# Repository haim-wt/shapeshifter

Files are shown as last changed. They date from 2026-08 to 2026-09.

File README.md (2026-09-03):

# Shapeshifter

A single-seat, folding, electric assisted glider — hang-glider freedom with
fly-by-wire safety, in a vehicle that drives itself to the launch point.

## The three modes

1. **Drive** — folded (3.9 × 2.5 m footprint), self-propelled on its wheels
   at scooter speeds. Off-road / field / garage-to-launch; not road-legal by
   design. Folded ground handling also removes the classic wind-on-the-ground
   hazard of foot-launched gliders.
2. **Unfold** — two automated fold stages (nested parallelogram
   linkages, all-vertical hinge axes, gravity-neutral), sensor-verified locks. The aircraft will not arm propulsion
   unless every lock confirms.
3. **Fly** — a 10 m joined-wing box glider, L/D ≈ 16–17, with twin electric
   tractor motors for takeoff (~50–70 m of grass), climb, go-around, and
   powered slow landings. Fly-by-wire with a hard flight envelope: stall is
   a software limit, not a pilot skill.

## Configuration at a glance

| | |
|---|---|
| Configuration | joined-wing box (Ligeti Stratos geometry), no tail boom |
| Span / area | 10.0 m / 13.0 m² (4 identical elements, one mold) |
| Empty weight | ~103 kg target (Part 103 cap: 115 kg / 254 lb) |
| Stall (landing config, camber flap) | ≤ 23 kt — Part 103 limit is 24 kt |
| Best glide | L/D ≈ 16–17 at ~16 m/s; min sink ≈ 0.9 m/s |
| Propulsion | 2 × ~3 kW tractor motors, folding props, rear wing LE |
| Battery | modular 2–4 × 0.9 kWh swappable packs + isolated actuator pack |
| Folded | 3.91 × 2.46 × 2.08 m — standard parking space |
| Regulatory | FAR Part 103 ultralight (no license, no certification) |
| Recovery | ballistic parachute (excluded from Part 103 empty weight) |

## Status

Concept definition. See [docs/spec.md](docs/spec.md) for the numbers,
[docs/fold-mechanism.md](docs/fold-mechanism.md) for the fold design,
[docs/mass-audit.md](docs/mass-audit.md) for the mass/battery ledger,
[docs/decisions.md](docs/decisions.md) for the decision record, and
[docs/exploration-history.md](docs/exploration-history.md) for how the
configuration was reached and what was rejected on the way.

## 1:10 printed model

Printable STLs for a Bambu P-series (256 mm cube) live in `models/1to10/`
(`tools/model_geometry.py`); editable STEP solids in `models/1to10/step/`
(`tools/model_step.py`, CadQuery); a native parametric Fusion 360 build
script in `tools/fusion360/`. Build plan, print counts, and test cards in
[docs/model-1to10.md](docs/model-1to10.md).

## Driving Fusion 360 directly

Autodesk's Fusion MCP server (Fusion: *Preferences > General > API > enable
Fusion MCP Server*, default port 27182) is registered in `.mcp.json` as a
project-scoped MCP server. It listens on loopback, so it is reachable only
from a Claude Code session running on the same machine as Fusion:

```
git clone <repo> && cd shapeshifter
git checkout claude/shared-conversation-review-vau7yj
claude            # approve the "fusion" MCP server when prompted
```

Then ask Claude to build the 1:10 model in the open Fusion design — it can
drive Fusion's API live instead of running the blind script in
`tools/fusion360/`.

## Next physical articles (in order)

1. Sub-scale fold mechanism (both parallelogram stages + locks) — the fold
   is the novel mechanism; prove 1-DOF behavior, lock integrity, and
   repeatability before any aerodynamic work.
2. Fin/tip node with stub wings, torsion-tested — the fin carries three
   jobs (joiner, yaw surface, wing-to-"tail" load path); its stiffness is
   the number the stability margin hangs on.
3. One full-scale wing element (D-nose, sail, camber flap, mid-span fold
   joint) — the entire aircraft in miniature.

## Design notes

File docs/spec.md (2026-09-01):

# Shapeshifter — Specification v0.2

Status: concept definition. Every number here is a target with a stated
derivation, not a measured value. Numbers that bind the design are marked
**(binding)**.

## 1. Mission

Single occupant. Drive folded from storage to an open field under its own
power, unfold, take off in ~50–70 m of grass, fly as a genuine glider with
electric assist (launch, saves, go-around, powered slow landing), land,
fold, drive away. Pilot supplies intent; fly-by-wire supplies control and
envelope protection.

## 2. Regulatory envelope — FAR Part 103 (binding)

| requirement | limit | our position |
|---|---|---|
| Empty weight, powered | 254 lb / 115 kg | ~103 kg target + 12 kg margin |
| Ballistic parachute | excluded from empty weight | fitted, ~7 kg physical |
| Power-off stall, landing config | ≤ 24 kt CAS | 22.6–23.1 kt (flap, see §5) |
| Max level speed | ≤ 55 kt | ~35 kt cruise, not binding |
| Occupants | 1 | 1 |

Consequences: no license, no certification, no medical — this is what makes
"as easy as riding a bike" legally true, and it is why Part 103 is a hard
target rather than a preference. It also means nobody certifies the
fly-by-wire system; every safety property is self-imposed (§9).

Fallback if mass discipline fails: MOSAIC LSA (effective 2025-10-22) allows
electric propulsion, no weight cap, 59 kt stall — but requires a sport-pilot
certificate and consensus-standard certification. Different product; avoid.

## 3. Configuration

Joined-wing box: front wing pair low and forward on the capsule, rear pair
high and aft (~1.5 m stagger = tail arm), tips joined by slanted fins.
Decalage ~2.5° makes the front pair stall first — pitch stability and stall
recovery are geometric, not commanded. Four identical wing elements from one
mold; front/rear differ only in root-fitting incidence.

- Span 10.1 m, area 13.0 m², chord 0.72 m constant
- Element per side: 0.24 m fixed root stub + 2.25 m inner panel + 2.25 m
  outer panel (equal spans — a fold requirement, see docs/fold-mechanism.md)
- Effective span ≈ 11.7 m (Prandtl box-wing), effective AR ≈ 10.5
- Section: D-nose torsion box to 30% chord, sail aft, ~14% t/c, morphing
  trailing edge (camber flap) on the front pair
- Moving aerodynamic surfaces in flight: 2 elevons (rear outboard, actuators
  in fin nodes) + camber flaps. Yaw: fins + differential thrust/regen.

## 4. Mass budget (binding — every line is a not-to-exceed)

| group | kg |
|---|---|
| 4 wing elements (13 m², D-nose + sail + flap) | 26 |
| Fins / tip nodes (2) | 6 |
| Fold system: 4 root pivots, 4 mid-span joints, locks, actuators | 12 |
| Capsule survival cell + canopy | 16 |
| Seat, harness, cockpit controls | 4 |
| Landing gear: 3 wheels, 2 hub motors, brakes, suspension | 13 |
| Propulsion: 2 motors, ESCs, folding props, mounts | 9 |
| Flight battery — LiTech 12S6P (RFQ), 1–3 × 1.12 kWh @ ~6.35 kg | 6.4–19.1 |
| Avionics, FBW actuators, actuator battery, wiring | 6 |
| **Empty (Part 103 accounting)** | **98.4–111.1** |
| Ballistic parachute (physical, excluded from Part 103 count) | +7 |
| Pilot (design range 60–100 kg) | +85 nominal |
| **Flying weight, nominal** | **~195 kg** |

Core empty (everything except battery) = 92 kg; battery fills the gap to
the 115 kg cap as swappable modules. Full audit, line justifications, and
the battery-as-residual-claimant rule: **docs/mass-audit.md**.

## 5. Speeds and compliance stall (binding)

At 195 kg flying weight, S = 13.0 m², sea level:

- Stall, clean, CLmax 1.5: 12.3 m/s = 23.9 kt — no margin. Therefore:
- **Stall, landing config, camber flap, CLmax 1.7: 11.9 m/s = 23.1 kt** ✓
  (at 100 kg pilot + chute: 23.5 kt ✓)
- The camber flap is REQUIRED for Part 103 compliance, not an option.
- Rotate ~13.5 m/s; approach ~1.3 Vs ≈ 15 m/s, reduced further by partial
  thrust unloading on final
- Best glide ~16 m/s, L/D ≈ 16–17; min sink ≈ 0.9 m/s at ~13 m/s
- Vne 40 m/s (structural placard, to be confirmed by aeroelastic analysis)

## 6. Propulsion and energy

- 2 × T-Motor P80 III KV100 (ag-drone class, >3.3 kW cont, IP55), rear
  wing leading edge at ±1.2 m, counter-rotating (tops inboard), Ø0.81 m
  (32") CF props — rigid on prototype, folding hub as product item;
  ESC: T-Motor Alpha 80A 12S FOC (LVC off, telemetry to FC)
- Static thrust ~380 N combined (~190 N/motor at ~3.5 kW); + wheel drive
  → grass takeoff roll ~50–60 m
- Climb ~1.0–1.3 m/s at full power (195 kg); one motor = full sustainer
- Cruise/sustain power: ~2.2 kW electrical → 27–80 min powered (1–3 packs); bus 12S (44.4 V nom / 50.4 V max)
- Energy reality: one climb to 500 m costs ~600–700 Wh. The pack buys one
  launch + saves + reserved go-around (~25 Wh, never spendable by the
  planner), or two modest launches. Soaring is the range extender.
- Regen: props windmill under regen for glide-path control (replaces
  spoilers) and descent recovery
- Ground drive: 2 hub motors, 25–40 km/h, ~20 Wh/km — ground range is
  effectively free relative to flight

## 7. Fold architecture (the novel mechanism)

Fully defined in **docs/fold-mechanism.md**; verified by the parametric
model `tools/fold_kinematics.py` (collision-checked through the complete
sequence); figure: docs/fold_sequence.png. Summary:

- Two nested parallelogram linkages, **all hinge axes vertical** → the fold
  is gravity-neutral; actuators are sized by wind (≤ 4 m/s fold limit),
  not by lifting panels.
- Stage 1: outer panels + fin double back 177° about mid-span knuckles
  (fin translates — parallelogram coupler). Stage 2: inner panels scissor
  88° **forward** about 240 mm root stubs; wings wrap the nose.
- **Folded: 3.91 × 2.46 × 2.08 m** — standard parking space.
- Flight loads cross every hinge perpendicular to its free axis: bearing
  couples carry bending (5–6 kN ultimate); locks carry only in-plane
  moments (< 0.7 kN). Two lock groups per side, spring-loaded to locked,
  position-sensed, tapered pins for zero freeplay.
- The fold owns one hull constraint: the footwell (first 0.8 m, below
  z ≈ 0.5) must stay ≤ 0.32 m wide — the doubled front-outer trailing
  edges sweep past it with 18 mm margin.
- Fold is ground-only: interlocked against airspeed and prop arming;
  propulsion cannot arm until all locks confirm and a control sweep passes.

## 8. Ground mode

- Tricycle: two main wheels (hub motors, regen + friction brakes) just aft
  of CG, ~1.1 m track; steerable nosewheel. No self-balancing single wheel:
  static stability, no balance energy, and a stable rollout platform for
  automated landings.
- Off-road self-mobility only (field, campground, private ways). Not
  road-legal, by decision — avoids automotive homologation entirely.
- Drive folded; unfold at the launch point. Deployed taxi is limited to
  walking pace by software (13 m² of wing in a gust is a kite).

## 9. Safety architecture

1. Envelope protection: alpha and load-factor limits in software; stall is
   unreachable by command. Elevon travel limiter implements the guarantee.
2. Redundancy: twin motors (one = sustainer; differential thrust is backup
   yaw/pitch authority after a control failure), dual elevon paths,
   isolated actuator/avionics battery (control survives total propulsion
   pack loss).
3. Interlocks: props cannot arm unless all 6 fold locks confirm + control
   sweep passes; fold cannot actuate with airspeed > 0 or props armed.
4. Ballistic parachute, capsule as survival cell: crushable nose,
   energy-absorbing seat sized for ~7 m/s descent under canopy.
5. Landing assist: powered slow approach (partial thrust unloading),
   propwash over elevons keeps control authority below free-flight stall,
   reserved go-around energy, auto-flare.

## 10. Open risks (ranked)

1. **Fin/tip-node stiffness** — the joined wing's stability margin and the
   propped-beam structural savings both assume a stiff fin loop. Physical
   torsion test before tooling.
2. **Fold-joint stiffness and freeplay** — 6 locked joints now sit in the
   primary structure; lash there is the flutter path. Budget < 0.5 mm at
   the lock, measured, per joint.
3. **Mass growth** — 12 kg margin against Part 103; every kg over cascades
   into the stall limit via §5.
4. **Aeroelastics of the final configuration** — no flutter analysis exists
   yet for the box with fold joints; required before Vne is trusted.
5. **Stage-1 fold collision/clearance geometry** — panels, fin, props, and
   capsule must clear through the full fold arc; resolve in CAD + sub-scale.
6. **Sail behavior at 13 m² with flap** — camber-flap CLmax 1.7 on a
   sail-over-D-nose section is assumed, not demonstrated; wind-tunnel or
   instrumented RC validation.

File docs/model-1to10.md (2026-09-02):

# 1:10 printed model — build plan

Printer: Bambu Lab P2S, 256 × 256 × 256 mm. Geometry: `tools/model_geometry.py`
→ `models/1to10/*.stl` (all watertight, all fit the bed, report in
`parts_report.json`). Preview: `docs/model_1to10_preview.png`.

## What this model is for — and what it is not

**Tests (worth building for):**
1. **The fold, with real locks.** Kinematics scale exactly, so both
   parallelogram stages, the forward scissor, the knuckle z-offset, and the
   lock sequencing are all faithfully represented. Note: *clearances scale
   too* — the full-scale 18 mm footwell margin becomes 1.8 mm here, inside
   print tolerance. If the model binds at the footwell, that is a finding
   about the full-scale margin, not a print defect: the answer is to widen
   the full-scale margin to ≥ 30 mm, not to file the model.
2. **Configuration stability.** Stagger as tail arm, decalage making the
   front pair stall first, spiral/Dutch-roll tendency with these fins —
   all visible in hand-glide tosses before any electronics go in.
3. **Elevon authority and the two-motor control backup** (phase 3).

**Does not test (do not draw conclusions):** aerodynamic coefficients
(Re ≈ 45k at this chord — the 14.3% section will run a laminar bubble and
glide at maybe L/D 6–8; full scale is Re ≈ 800k), flutter, the sail
structure (printed skins are rigid), mass properties, or actuator loads.

## Geometry at 1:10

| item | full scale | model |
|---|---|---|
| Span | 10.1 m | 1,010 mm |
| Chord | 0.72 m | 72 mm |
| Root stub / inner / outer panel | 0.24 / 2.25 / 2.25 m | 24 / 225 / 225 mm |
| Stagger / gap | 1.50 / 1.40 m | 150 / 140 mm |
| Fin | 2.05 m × 0.35 m, 12% | 205 × 35 mm |
| Pod | 2.1 × 0.74 × 1.4 m | 210 × 74 × 140 mm |
| Outer-panel washout | 3° | 3° (built into the STL) |
| Decalage | front +2.5° vs rear | built into `root_stub_front` |
| Knuckle z-offset | 120 mm | 12 mm (`hinge_lug_offset`) |
| Wing area | 13.0 m² | 0.135 m² |

## Parts and print counts

| STL | qty | material | orientation / notes |
|---|---|---|---|
| `wing_inner` | 4 | LW-PLA | span-vertical, as printed (no twist → not chiral) |
| `wing_outer` | 2 + 2 **mirrored** | LW-PLA | span-vertical. **Chiral:** washout has handedness. Print 2, then mirror in Bambu Studio **along Z (the print/span axis)** and print 2. Do NOT mirror X — that reverses the chord. (The STEP set ships `wing_outer_L` and `_R` pre-mirrored.) |
| `fin_blank` | 2 | LW-PLA or PLA | vertical; 3.2 mm spar hole |
| `root_stub_front` / `_rear` | 2 + 2 | PETG | these carry the decalage; glue to pod |
| `capsule_pod` | 1 | PLA / PETG | lying on its side; 3 walls, 0–4% infill; nose taper *is* the footwell (fold-critical) |
| `hinge_lug` | 24 | PETG | flat; 3.2 mm hole for M3 pins |
| `hinge_lug_offset` | 8 | PETG | flat; the 12 mm knuckle z-offset lugs |

Slicer settings for the LW-PLA airfoils: 2 walls (0.42 mm), 0% infill,
no top/bottom layers except 2 at the ends, 0.16–0.20 mm layers, LW-PLA
foaming temp per the filament (typically 230–250 °C, flow ~50%), dry the
spool, slow (≤ 60 mm/s). Spar and pin holes are through-holes along the
print axis, so they print clean without supports.

## Hardware (glider phase)

- Spars: 8 × carbon tube Ø5 × 225 mm (one per panel; the fold joints break
  the spar, as they do full scale). Alignment pins: 8 × carbon rod Ø2 × 30 mm.
- Fin spars: 2 × carbon rod Ø3 × 205 mm.
- Fold pins: M3 × 16 screws with nyloc nuts as hinge pins (12 knuckles: 4 root
  pivots, 4 mid-span knuckles, 4 fin-tip hinges). Fold locks: 4 mm Ø
  neodymium magnet pairs at the deployed position (phase 1), replaced by a
  9 g servo-driven pin (phase 2) to test the interlock logic.
- CA + kicker for PETG lugs to LW-PLA; epoxy for spars in the pod stubs.

## Mass and CG

Estimate: 8 panels ≈ 140 g, fins 16, pod ≈ 70, stubs 8, lugs/pins 25,
spars 40 → **~300 g airframe.** Glider-phase electronics (4 × 9 g servos,
RX, 1S 500 mAh) ≈ 60 g → ~360 g before ballast. Powered (phase 3): + 2 ×
(2204 motor, 12 A ESC, 5" prop) + 3S 850 mAh ≈ +210 g → ~570 g.

Wing loading ≈ 4.2 kg/m² powered → flies at ~9–12 m/s. That is faster than
Froude scaling would give (~4 m/s) because the model is ~3× "scale weight";
expected and acceptable — the fold and the stability signatures do not
depend on it.

**First CG guess: 115–120 mm aft of the nose** (≈ 10% of the stagger ahead
of the estimated neutral point at ~130 mm, taking the rear pair at ~70%
efficiency in the front pair's downwash). Start nose-heavy; move aft by
5 mm steps on glide tosses until the glide flattens without hunting.

## Build phases and test cards

**Phase 1 — bench article (no electronics).** Print, spar, assemble both
sides on the pod with magnet locks. Tests: (a) fold both stages by hand;
photograph every interference; (b) measure freeplay at each lock with a
dial indicator against the panel tip; (c) hang 200 g at each tip node
deployed — the propped-beam box should barely deflect; note any joint
that opens. Record in `docs/test-log.md` (create on first test).

**Phase 2 — hand-glide.** Ballast to CG, toss on grass. Looking for:
straight glide, no pitch hunting (decalage working), no wing-drop at the
end of the glide (front stalls first), spiral tendency. Then deliberately
mis-rig: rear stubs at 0° vs front 0° (no decalage) to confirm it matters.

**Phase 3 — RC.** Elevons on the rear outer panels (cut 25% chord, tape
hinges — the flexure idea, cheaply), 2 motors on the rear inner panels at
±120 mm, differential-thrust yaw. Fold servos + lock pins with the
"cannot arm unless locked" interlock in the flight controller — the
first end-to-end exercise of the safety logic.

## Fusion 360 / CAD workflow

Three routes, from quickest to most editable:

1. **STL** (`models/1to10/*.stl`) — slice and print. Not editable.
2. **STEP** (`models/1to10/step/*.step`, from `tools/model_step.py` via
   CadQuery/OpenCascade) — true B-rep solids. *File > Insert > Insert
   Derive* or drag into Fusion: they land as editable bodies you can add
   fillets, pockets, and joints to. This set is one revision ahead of the
   STLs: **hinge-lug pockets are cut into every panel end** on the 25% chord
   line (5.4 × 10 mm deep, through the section) so lugs register instead
   of being placed by eye; the spar hole sits on the twist axis; alignment
   pins are 20 mm blind holes at each end; `wing_outer_L/R` are both
   provided.
3. **Native parametric** (`tools/fusion360/Shapeshifter1to10/`) — a Fusion
   360 API script that rebuilds everything as Fusion features with user
   parameters (`ss_chord`, `ss_inner`, `ss_washout`, `ss_decalage`, …).
   Copy the folder into Fusion's `API/Scripts/` directory, open a new
   design, *Utilities > Add-Ins > Scripts > Run*. Edit any `ss_*` value in
   *Modify > Change Parameters* and the model regenerates. This script was
   written without a Fusion instance to test on; if it errors, paste the
   traceback from the message box and it will be fixed.

## Known limitations of this geometry (v0)

- Panels are solid lofts; skins come from slicer wall settings, not modeled
  ribs. Fine for LW-PLA at this size.
- STL panels have no lug pockets (placement by hand at 25% chord); the
  STEP and Fusion versions do.
- Pod is a clean loft with no canopy line, hatch, or gear — a shape and
  mass placeholder. The nose taper approximates the footwell requirement.
- No nacelles yet; phase-3 motors mount on printed saddles.

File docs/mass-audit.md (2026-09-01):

# Mass audit v1 — every kilogram justified, battery as the residual claimant

Goal restated: the point of mass discipline is not a lighter vehicle — it is
**more battery**. This document sets the algebra that converts saved mass
into energy, then justifies every line.

## 1. The constraint algebra

Three independent caps:

1. **FAA empty weight** (Part 103): empty ≤ 115 kg, *battery included*,
   ballistic chute excluded.
2. **Stall** (Part 103, landing config ≤ 24 kt): at S = 13 m², CLmax 1.7
   → max flying weight **210 kg** (we operate to 205 for margin).
3. **Folded envelope** (parking space): fixed by the fold design, not mass.

Define **core empty = everything except battery**. Then:

- **Max battery = 115 − core.** Today core = 92 kg → max battery 23 kg.
- **At full battery, max pilot = 205 − 115 − 7 (chute) = 83 kg** — and this
  is *invariant*: shrinking core raises battery, not pilot allowance.
  Heavier pilots fly with fewer modules (see §3).

**The exchange rate: 1 kg of core saved = 1 kg of battery = ~160 Wh
= ~95 m of powered climb or ~4 min of sustain.** Every design argument
about mass now terminates in this number.

## 2. Line-by-line justification (core = 92 kg)

| line | kg | basis | confidence | path to battery |
|---|---|---|---|---|
| Wing panels, 4× (13 m² total) | 26 | 2.0 kg/m², D-nose + sail + battens + flap; comparable: ATOS-class rigid wings ~2.3 kg/m² incl. control frame | med | none — already aggressive; growth risk +2 |
| Fins / tip nodes, 2× | 6 | 0.7 m² surface + elevon actuator + propped-beam reaction fitting each | med | none; growth risk +2 (stiffness-critical part) |
| Fold system | 12 | model-derived: 4 root pivots (bearing couples @5.7 kN ult) ~1.3 ea; 4 mid knuckles (@5.3 kN) ~0.9 ea; 6 locks ~0.25 ea; 4 fold drives ~0.45 ea | med-high (loads computed) | **−1**: gravity-neutral fold means sub-kg drives; consolidate stage-1 drive to one side at a time |
| Capsule cell + canopy | 16 | 2.1 m carbon monocoque + bubble; sailplane forward-fuselage comparables 12–18; crash cell adds | med | none — safety-critical line |
| Seat, harness, controls | 4 | includes energy-absorbing seat stroke (chute descent ~7 m/s) | high | none |
| Landing gear + ground drive | 13 | 3 wheels, suspension, brakes + 2 hub motors @3.5 kg | high | **−3**: one driven main + freewheel + steered nose. Ground spec (30 km/h, grass) needs ~2 kW, not two motors. Takeoff traction: verify single-wheel slip on wet grass before committing |
| Propulsion | 9 | 2 × 3 kW outrunners ~1.4 ea, ESCs, Ø1.05 folding props ~0.9 ea, over-wing mounts | high | none |
| Avionics + FBW | 6 | 2 elevon + 2 flap actuators, FC + IMU + air data, isolated 150 Wh actuator pack (~1.0), wiring | med | none; growth risk +1 (wiring always grows) |
| **Core empty** | **92** | | | **identified: −4 → core 88** |

Growth risks total +5; identified savings −4. Honest expectation: core
stays 88–95. **Rule from here: any kilogram added must name the kilogram
it displaces or the watt-hours it forfeits.** Battery absorbs every saving
and every bust — it is the flexible line, by design.

## 3. Battery architecture: modular, and the W&B is measured

**Selected: LiTech 12S6P (RFQ from adopted 13S6P design) — 1–3 swappable
packs × ~1.12 kWh, ~6.35 kg each (~176 Wh/kg, CAN BMS, IP65).** Bus: 12S,
44.4 V nom / 50.4 V max. See docs/parts-log.md. One-hand carry, charge
off-vehicle, no charging infrastructure needed at the field.

The vehicle weighs itself: load cells in the three gear legs give total
weight and CG at power-on. Software enforces MTOW 205 kg and CG limits —
module count is the trim variable:

| pilot | packs | battery | flying wt | powered endurance* | cumulative climb* |
|---|---|---|---|---|---|
| ≤ 87 kg | 3 | 3.35 kWh | ≤ 205 | ~80 min | ~1730 m |
| ≤ 93 kg | 2 | 2.23 kWh | ≤ 205 | ~53 min | ~1150 m |
| ≤ 100 kg | 1 | 1.12 kWh | ≤ 205 | ~27 min | ~580 m |

*usable 88% of nominal; sustain ~2.2 kW; climb conversion ~0.32 (drag paid
during climb); go-around reserve (~25 Wh) always withheld by the planner.

This turns the Part 103 weight problem into a UX feature: the aircraft
tells you how many modules today's pilot + mission can carry, and refuses
to arm overweight. Nothing is placarded on trust.

## 4. What we deliberately do NOT chase

- Sub-2.0 kg/m² wings, exotic capsule layups, titanium anything: each buys
  1–3 kg at large cost and schedule risk; the same money buys pack-level
  Wh/kg, which scales all four modules at once.
- Removing the second flight motor: −4.5 kg, but redundancy is a standing
  owner decision (D-006).
- Removing gear/suspension travel: it is the landing-assist crumple margin
  and the W&B sensor mount.

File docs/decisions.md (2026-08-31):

# Decision record

Short, dated entries. A decision stands until a dated entry reverses it.
(The exploration phase showed why this file exists: good decisions were
made, lost, and re-derived. Not again.)

## D-001 · 2026-08-31 · Regulatory envelope: FAR Part 103, hard target
No pilot license, no certification, no medical — the only regime where the
product promise is legally true. Consequences: 115 kg empty cap, 24 kt
stall in landing configuration, single seat. MOSAIC LSA is the documented
fallback, treated as product failure, not an option to drift toward.

## D-002 · 2026-08-31 · Configuration: joined-wing box, four elements
Front pair low/forward, rear pair high/aft, slanted fin joiners. Chosen for:
(a) folds as a linkage — the closed loop is 1-DOF when hinged; (b) no tail
boom; (c) propped-beam structure → light spars; (d) box-wing span
efficiency; (e) geometric (not commanded) stall recovery via stagger +
decalage. Precedent: Ligeti Stratos.

## D-003 · 2026-08-31 · Fold: two nested parallelograms, three locks/side
Stage 1 transverse (outer panels + fin fold inboard), stage 2 plan-view
scissor. Chosen over: single-stage scissor (folds to ~6.7 m — fails the
parking-space requirement) and span reduction to ~7 m (destroys glide
performance the product depends on). Fold is ground-only; interlocked
against propulsion arming.

## D-004 · 2026-08-31 · Folded footprint target: standard parking space
~4.4 × 1.9 m. Drives the two-stage fold (D-003). Scooter-class width was
considered and rejected as the driver — it would force skewed-hinge
complexity everywhere; kept as a possible refinement of stage 2 only.

## D-005 · 2026-08-31 · Ground mode: off-road self-mobility, tricycle gear
Not road-legal, by design — automotive homologation is the trap that killed
prior roadable aircraft. Two driven mains + steerable nose; no
self-balancing single wheel (energy, failure modes, and landings need a
statically stable platform). Drive folded; deployed taxi speed-limited.

## D-006 · 2026-08-31 · Propulsion: two tractor motors on the rear wing
Twin ~3 kW, counter-rotating, folding props, ±1.2 m from centerline.
Redundancy is the requirement (owner decision, exploration phase): one
motor is a full sustainer; differential thrust is backup control authority.
Single pylon prop (better L/D) rejected for single-point failure. Ducted
fans rejected: ~2 points of L/D for stopped-duct drag.

## D-007 · 2026-08-31 · Camber flap on front pair is compliance-critical
At realistic flying weight the clean wing stalls at ~23.9 kt — inside
measurement error of the Part 103 limit. The morphing trailing edge
(CLmax ≥ 1.7 in landing config) is what puts stall at ≤ 23.1 kt with
margin. It is a required system, sized and tested as such.

## D-008 · 2026-08-31 · Battery is the residual claimant of all mass
Goal is maximum battery, not minimum weight. Core empty (no battery) = 92 kg
target; battery = 115 − core, carried as 2–4 swappable ~0.9 kWh modules.
Gear load cells measure weight & CG at power-on; software enforces MTOW 205
and CG — module count is the trim variable (heavier pilot, fewer modules).
Rule: any kg added must name the kg it displaces or the Wh it forfeits.

## D-009 · 2026-08-31 · Fold: all-vertical axes, double-back + FORWARD scissor
Both stages are parallelograms with vertical hinge axes: gravity-neutral,
max height 2.1 m throughout, 1-DOF per stage. Scissor sweeps FORWARD —
forced by the chord-flip trap (doubling flips outer-panel chords; aft sweep
buries the front inner TE in the cabin — model-verified, unfixable).
Consequences owned: 240 mm fixed root stubs (swing-arc clearance), equal
2.25 m panel spans, nacelles above the wing plane, and a hull footwell
≤ 0.32 m wide over the first 0.8 m. Folded 3.91 × 2.46 × 2.08 m.
Carrier-style over-the-top folding rejected: gravity-fighting actuators,
4 m height excursion, 2-axis mid joints.

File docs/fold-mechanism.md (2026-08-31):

# Fold mechanism — design definition v1

Derived and verified with `tools/fold_kinematics.py` (parametric plan-view
kinematics with z-band collision checking through the full fold sequence).
Sequence figure: `docs/fold_sequence.png`.

## Architecture: two nested parallelograms, all hinge axes vertical

**Stage 1 — double-back.** Each side's outer-panel pair + fin rotates 177°
about vertical axes at the mid-span knuckles. The fin is the coupler of a
parallelogram four-bar (equal outer spans, tip separation = knuckle
separation), so it translates without rotating. Outer panels end doubled
back over the inner panels, raised 120 mm by an offset knuckle.

**Stage 2 — forward scissor.** Each side's inner-panel pair (carrying its
folded bundle) rotates 88° **forward** about vertical axes on the root
stubs. Same parallelogram logic; the folded bundle is the coupler. The
wings end up wrapped around the nose, hull in the middle of the package.

**Folded envelope: 3.91 × 2.46 × 2.08 m** — inside a standard parking
space. Deployed span 10.1 m (0.24 stub + 2.25 inner + 2.25 outer per side).

## Why these choices (each was forced, not preferred)

1. **All hinge axes vertical → the fold is gravity-neutral.** Panels swing
   in plan on their bearings; no actuator ever lifts a panel. Fold
   actuators are sized by *wind* on the swinging panel, not gravity:
   ~65 N·m (stage 1) / ~115 N·m (stage 2) for folding in up to 4 m/s wind
   — sub-kilogram motors. The alternative (carrier-style over-the-top
   folding) costs ~130 N·m of continuous gravity torque per joint, a 4 m
   height excursion mid-fold, and 2-axis mid joints. Rejected.
2. **Forward scissor, not aft — forced by the chord-flip trap.** Doubling a
   panel back 180° in plan flips its chord. After the scissor, inner-panel
   trailing edges point one way and outer-panel TEs the other; whichever
   sweep direction clears the inners buries the outers. Model result:
   aft sweep buries the front inner TE in the cabin (unfixable); forward
   sweep leaves only the front *outer* TE low near the hull — fixable (next
   item). Verified: aft collides at φ=27°, forward runs clean.
3. **Narrow footwell — a hull constraint owned by the fold.** The doubled
   front-outer TEs sweep through y ≥ ±0.18 m at z 0.30–0.45 over the first
   0.8 m of hull. The hull must be ≤ 0.32 m wide there. Anthropometry
   allows it (two feet side by side ≈ 0.30 m); the capsule spec now carries
   this as a frozen interface. Min clearance through the full sequence:
   18 mm — tight; recover with footwell −20 mm or stub +20 mm if CAD needs it.
4. **240 mm fixed root stubs — forced by the swing arc.** Any chordwise
   overhang ahead of a vertical hinge sweeps an *arc* inboard during
   rotation (LE corner dips 137 mm past the hull wall with roots on the
   hull). The stub moves the arc clear and gives the root bearing pair a
   rigid home. (This resurrects the exploration's "fixed center section.")
5. **Equal inner/outer spans (2.25/2.25)** — the outer folds back exactly
   onto the inner, its tip landing at the stub; unequal spans left the
   folded tip's TE corner grazing the hull by 7 mm mid-scissor.
6. **Nacelles above the wing plane** — slung under the LE they sweep the
   canopy top during the scissor; above the LE they clear (and precedent
   for over-wing pods on self-launchers is good).

## Joints and loads (from the model, ultimate)

| item | free axis | carries via bearings | lock carries |
|---|---|---|---|
| Root pivot (×4) | vertical | flap bending 1.14 kN·m → 5.7 kN couple (200 mm spacing) | in-plane moment incl. prop thrust: 0.63 kN link load |
| Mid knuckle (×4) | vertical | flap bending 0.80 kN·m → 5.3 kN couple (150 mm spacing) | in-plane moment: 0.28 kN pin load |

Key property, worth stating twice: **flight loads cross every hinge
perpendicular to its free axis.** Bearings (preloaded, zero-clearance)
carry bending and torsion; locks carry only small in-plane moments. The
locks are sub-kilonewton pins — the exploration's design rule ("bearings
carry bending; the constrained axis carries only its own load") holds at
every joint.

- Locks: 2 groups per side — one tapered pin + over-center toggle at each
  mid knuckle TE, one over-center drag strut at the scissor. Spring-loaded
  toward locked, position-sensed, tapered engagement for zero freeplay.
  Freeplay budget: ≤ 0.5 mm at each lock, measured, per preflight.
- 1-DOF per stage per side → one lock rigidifies each stage; the second
  pin at the mid knuckle is redundancy, not kinematic necessity.

## Sequence and interlocks

Unfold: (1) stubs live, scissor drives forward→deployed, scissor struts
over-center + pinned; (2) stage-1 knuckles drive outers out, TE pins seat;
(3) controller sweeps all surfaces, reads all 6 lock sensors + 4 knuckle
encoders, then and only then allows propulsion arming. Fold is the reverse,
permitted only at zero airspeed, props stopped and folded, on wheels.
Operational limit: no folding above 4 m/s wind (actuator sizing case;
above that, wait or point nose into wind).

## Open items

1. 18 mm minimum hull clearance → re-verify in surfaced CAD with real hull
   curvature (box model is conservative inboard, optimistic at corners).
2. Wiring: CAN + power to outer panels and fin (elevon actuator lives in
   the fin node) crosses two vertical-axis joints → service loops on the
   hinge axes, hard travel stops; no slip rings.
3. Sail continuity at the mid knuckle: sail is per-panel (decided in
   exploration); the knuckle gap needs a shroud that tolerates ±177°.
4. Stage-1 drive synchronization L/R (fold one side at a time is
   acceptable and halves actuator count — decide at prototype).
5. Sub-scale mechanism prototype (1:5): prove lock seating repeatability,
   measure real freeplay, confirm the parallelogram tracks under sail loads.

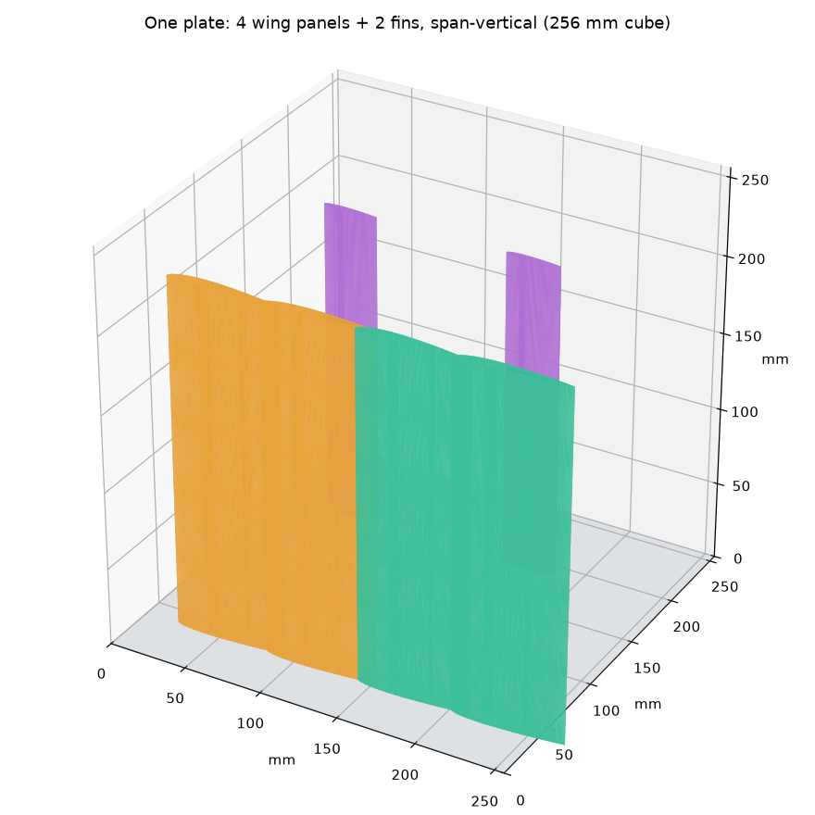
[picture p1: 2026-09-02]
docs/model_1to10_preview.png

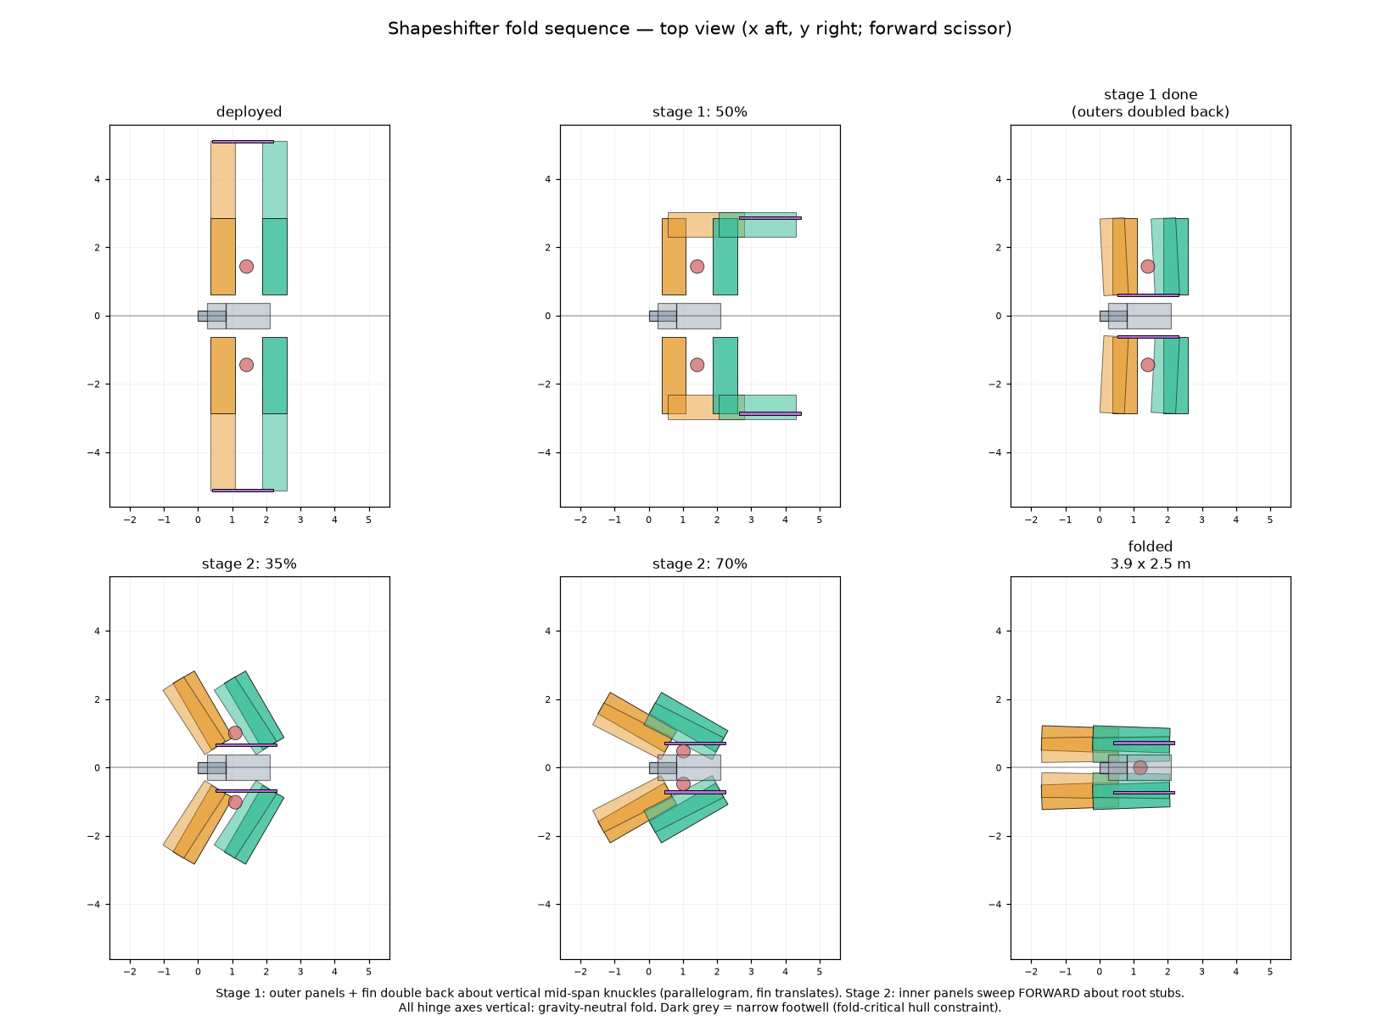
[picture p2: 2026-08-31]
docs/fold_sequence.png

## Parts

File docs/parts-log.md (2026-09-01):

# Parts evaluation log

Every candidate part gets a verdict here, so rejections don't get re-shopped
and accepted parts carry their caveats. Format: date · part · verdict · why.

## Batteries

**2026-08-31 · WattCycle 12V 314Ah Mini LiFePO4 (4.0 kWh, 27 kg, 200 A BMS, ~$510)**
Verdict: **NO for flight / YES for ground.** One 27 kg brick exceeds the
entire 23 kg battery allowance and kills the modular W&B scheme; 12.8 V bus
means 400+ A at climb power (BMS caps at 200 A); LiFePO4 ~149 Wh/kg claimed.
Excellent as the field charging station (4 kWh ≈ one full recharge of the
3.6 kWh module set, $127/kWh), bench power, and ground-mule battery.

**2026-08-31 · AliExpress "48V 100Ah citycoco pack", claimed 3 kg**
Verdict: **FRAUD.** 4.8 kWh at 3 kg = 1,600 Wh/kg, ~6x the best cells that
exist. Listing-quality tell; do not buy batteries with impossible density.

**2026-08-31 · Fullymax 12S 44.4V 22Ah smart pack (978 Wh, 6.5 kg, 20C, $769)**
Verdict: **YES — prototype flight battery, 3 per aircraft.** Purpose-built
ag-drone flight pack, smart BMS (cycle logging, auto-storage, firmware),
150 Wh/kg. 3 packs = 19.5 kg / 2.93 kWh -> empty 111.5 kg, inside the
115 kg cap; ~70 min sustain / ~1,450 m cumulative climb. Consequence:
**propulsion bus frozen at 44.4 V nominal (12S)** — size ESCs and motors
to it. Caveats: ~200-cycle life (yearly replacement in service — prototype
only), 20C power-cell weight penalty vs energy cells (~0.5 kWh forfeited
vs custom 21700 modules at equal mass), LiPo fire discipline (contained
module bays, charge off-vehicle). Verify weight and true capacity on
receipt. Production path remains custom energy-optimized 21700 modules.

**2026-09-01 · LiTech LP13S6P17A150AL001 — 13S6P li-ion, 48V/25.2Ah/1210 Wh,
CAN/RS485/BT BMS, IP65 metal case, ~150 A cont. (per part-number code), OEM**
Weight confirmed: **6,800 g ±30 g → 177.9 Wh/kg** — beats the module spec
(157) and Fullymax (150), with IP65 metal case and CAN included. Internally
consistent: 78 x ~4.9 Ah 21700 energy cells (~5.5 kg) + 1.3 kg case/BMS.
Verdict: **ADOPTED as the flight battery** (displaces Fullymax, which is
struck). Aircraft fit: 3 packs = 20.4 kg / 3.63 kWh -> empty 112.4 kg
(2.6 kg under the Part 103 cap), ~87 min sustain / ~1,870 m cumulative
climb, max pilot ~85 kg; 2 packs -> pilot ~92 kg; 1 pack -> ~99 kg. Climb
draw 42 A/pack vs ~150 A rating; any single pack sustains level flight.
Verify on receipt: shipped weight incl. connectors, actual cell model and
its continuous discharge rating (150 A is decoded from the part number,
unconfirmed), UN38.3.

**Bus voltage FROZEN: 13S — 48.1 V nominal, 54.6 V max.** All propulsion
components (motors, ESCs, wiring, contactors) sized to 54.6 V. Do not mix
pack types on one aircraft.

## Motors

**2026-09-01 · BadAss 6245-155Kv outrunner ($300, giant-scale RC)**
Verdict: **NO — Kv mismatch.** 155 Kv on the 13S bus = ~5,800 rpm loaded;
our O~1.05 m folding props need 2,000-2,400 rpm. Flying it means either a
~0.5 m prop (static thrust drops ~35%, grass takeoff stretches from
~60 m to 120+ m — kills the short-field story) or a 2.5-3:1 belt redrive
in the nacelle (rejected class of solution). Likely also 12S-max rating vs
our 54.6 V bus ceiling. Same lesson as the e-bike motor in the exploration,
mirrored: match the motor to the prop's rpm, then shop.

**Motor filter (frozen):** Kv 50-65 · rated >= 54.6 V (14S label) ·
>= 3 kW continuous / ~4 kW 30 s · ~13 N.m continuous · <= 2 kg ·
tractor mount, folding-prop hub. This lives in the paramotor /
heavy-lift-drone catalog (O120-155 mm outrunners: MAD M-series, T-Motor
U15 family, Hacker Q150 class), not giant-scale RC.

## ESCs

**2026-09-01 · T-Motor Alpha 80A 12S FOC ESC ($130, 110 g, 80 A cont / 100 A 10 s)**
Verdict: **NO — voltage ceiling 52.2 V vs our 54.6 V (13S full charge).**
Right class in every other respect (current margin over 62 A climb draw,
FOC, companion series to the U-family motors our filter targets). Pick the
14S/HV sibling instead.

**ESC filter (frozen):** rated >= 14S / 58 V · >= 80 A continuous ·
FOC · telemetry out (current/temp/rpm) to the FC · low-voltage cutoff
configurable OFF (the energy manager owns sag decisions, never the ESC) ·
<= 200 g · nacelle-mountable with propwash cooling.

## Bus decision, final

**2026-09-01 · Bus RE-FROZEN at 12S: 44.4 V nominal, 50.4 V max.**
Owner call: trade ~7% pack energy for the mainstream 12S component catalog
(ESCs, motors, chargers). Supersedes the 13S freeze. Consequences:

- **Battery:** RFQ LiTech for a 12S6P build of the adopted pack (same
  21700 energy cells, CAN BMS, IP65): est. 1,117 Wh / ~6.35 kg / 176 Wh/kg.
  3 packs = 19.1 kg / 3.35 kWh -> empty ~111 kg (4 kg under the cap).
  Endurance: ~80 min sustain / ~1,730 m cumulative climb (3 packs);
  max pilot at 3 packs ~87 kg, 2 packs ~93 kg, 1 pack ~100 kg.
- **ESC:** T-Motor Alpha 80A 12S FLIPS TO ADOPTED-CANDIDATE (52.2 V rating
  clears 50.4 V full charge). Climb draw 68 A vs 80 A continuous -
  propwash-cooled, acceptable; go-around at 4 kW = 90 A exceeds continuous,
  sits inside the 100 A/10 s peak -> firmware caps sustained go-around at
  3.5 kW/motor (79 A). Verify before adoption: LVC configurable OFF,
  telemetry via Alpha Data Link into the FC.
- **Motor filter, revised:** Kv 55-70 (2,200 rpm loaded at 44.4 V) ·
  rated >= 12S / 50.4 V · >= 3 kW cont · ~13 N.m · <= 2 kg · folding-prop
  tractor mount. Same paramotor/heavy-lift shelf; BadAss 6245-155Kv
  remains rejected (Kv still ~2.3x too high).

**2026-09-01 · T-Motor P80 III KV100 (12S, >3.3 kW cont, ~640 g, IP55, ~$260)**
Verdict: **ADOPTED-CANDIDATE — closes the propulsion chain.** Ag-drone
motor built for continuous load; pairs natively with the Alpha 80A 12S ESC.
Chain: LiTech 12S pack -> Alpha 80A FOC -> P80 III KV100 -> 32" CF prop.
Filter amendment: the Kv 55-70 filter assumed the O1.05 m prop; the correct
filter is the motor+prop PAIR: >=190 N static per axis at <=3.5 kW,
cruise-capable, <=2 kg. P80III + 32x11 passes: ~190 N/motor static,
~380 N combined + ~250 N wheel drive -> ~50-60 m grass takeoff at 195 kg;
climb ~1.3-1.5 m/s; cruise 25 A/motor. Propulsion group underruns its 9 kg
line by ~2-3 kg -> battery headroom (D-008). Open items: folding hub for
32" blades (prototype flies rigid props, ~1 L/D point penalty); confirm
real continuous thermal rating in the nacelle; KV100 variant, not KV120.
Prop spec changes: O0.81 m (32"), ~3,200 rpm loaded, tip Mach ~0.41.

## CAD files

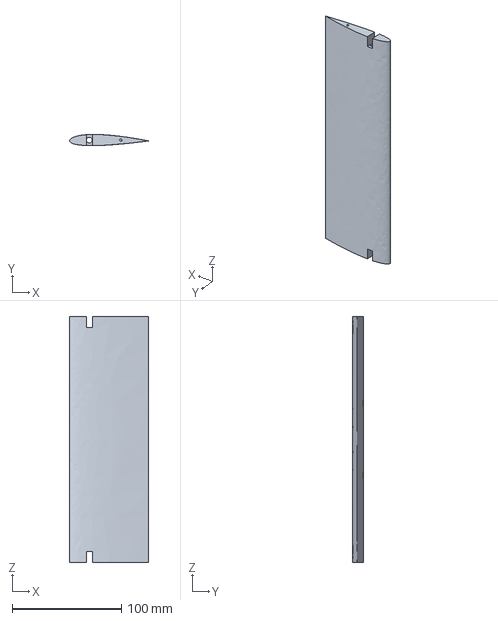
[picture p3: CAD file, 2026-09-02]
models/1to10/step/wing_inner.step
72.0 x 10.3 x 225.0 mm

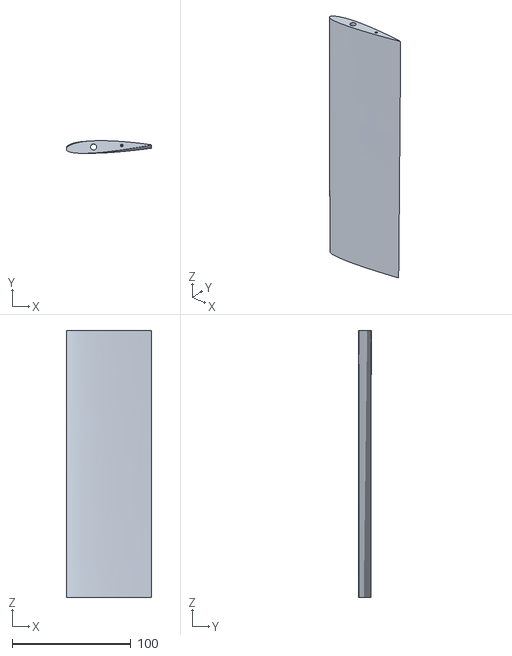
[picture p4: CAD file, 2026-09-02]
models/1to10/wing_outer.stl
72.0 x 10.7 x 225.0

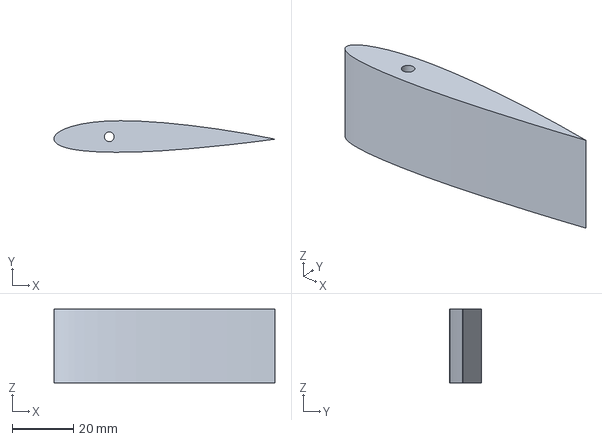
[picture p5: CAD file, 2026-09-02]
models/1to10/step/root_stub_rear.step
72.0 x 10.3 x 24.0 mm

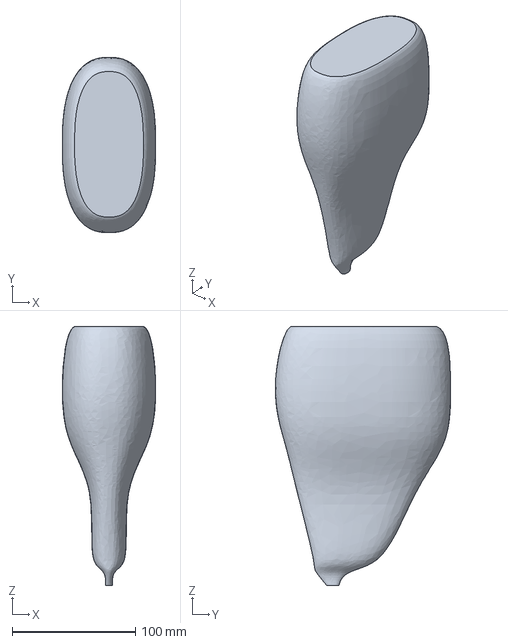
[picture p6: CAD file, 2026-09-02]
models/1to10/step/capsule_pod.step
75.8 x 142.1 x 210.0 mm

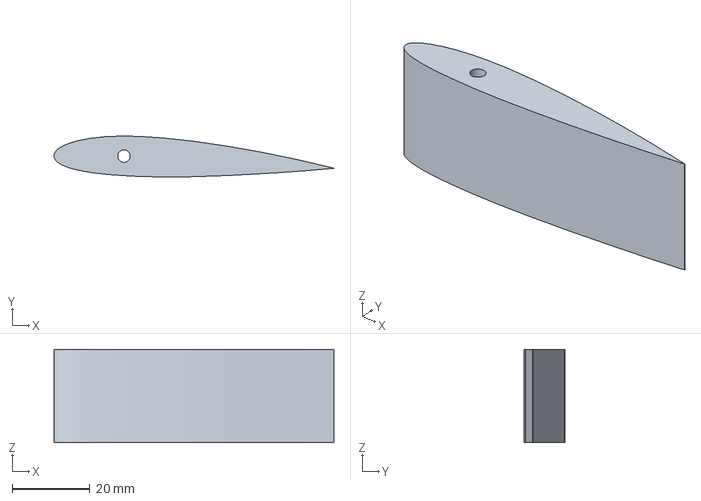
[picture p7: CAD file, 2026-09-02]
models/1to10/step/root_stub_front.step
71.9 x 10.5 x 24.0 mm

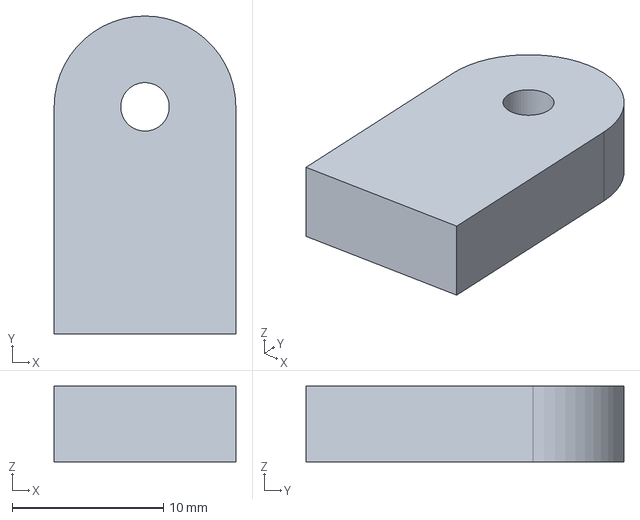
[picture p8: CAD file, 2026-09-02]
models/1to10/step/hinge_lug_offset.step
12.0 x 21.0 x 5.00 mm

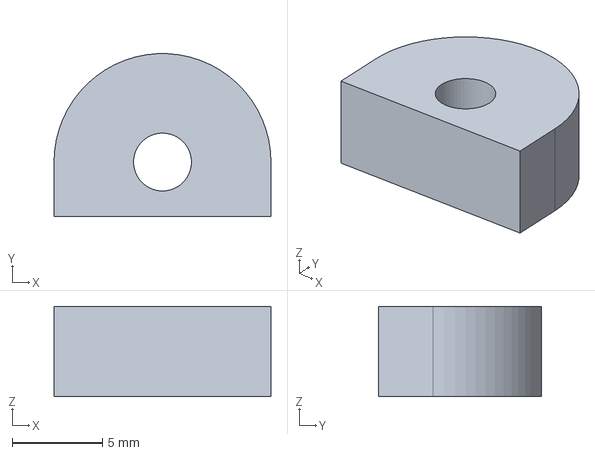
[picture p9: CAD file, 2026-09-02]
models/1to10/step/hinge_lug.step
12.0 x 8.99 x 5.00 mm

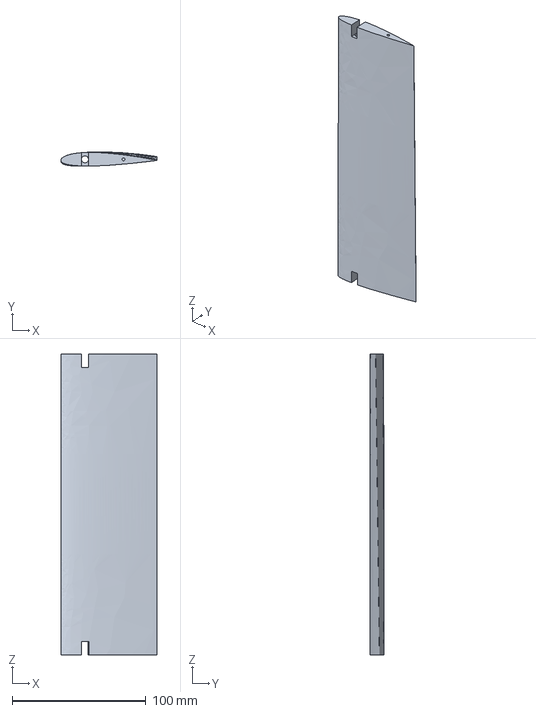
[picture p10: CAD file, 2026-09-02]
models/1to10/step/wing_outer_L.step
72.0 x 10.7 x 225.0 mm

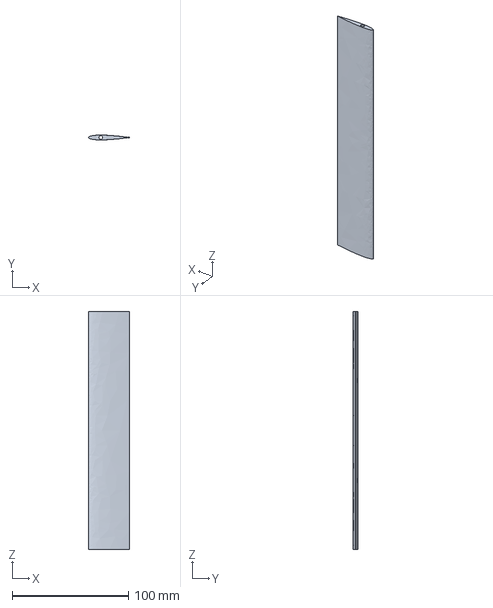
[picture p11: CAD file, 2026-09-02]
models/1to10/step/fin_blank.step
35.0 x 4.20 x 205.0 mm

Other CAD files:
models/1to10/step/wing_outer_R.step
models/1to10/capsule_pod.stl
models/1to10/fin_blank.stl
models/1to10/hinge_lug.stl
models/1to10/hinge_lug_offset.stl
models/1to10/root_stub_front.stl
models/1to10/root_stub_rear.stl
models/1to10/wing_inner.stl

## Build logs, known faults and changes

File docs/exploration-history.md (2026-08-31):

# How we got here — exploration summary

Condensed from the design exploration conversation (Aug 2026). Recorded so
the reasoning survives; each rejected branch names why, because several
"new" ideas will turn out to be these.

## The arc

e-bike motor pushing a hang glider → powered flying wing with motorized
surfaces → rigid pilot mount, fly-by-wire → all-moving wing panels on
robotic actuators (CubeMars AK class) → three-section rotating wing →
morphing sail wing (D-nose + bending trailing edge, 6 actuators) →
sectioned wing, actuators local per section → four-element box wing,
actuated at both ends → "assisted glider" reframing (e-bike principle) →
fixed joined wing + 2 elevons, intelligence in software → + folding,
wheels, capsule = Shapeshifter.

## Rejected branches and why

| branch | killed by |
|---|---|
| E-bike hub/mid-drive motor | RPM mismatch (500 vs 2800), torque reaction |
| Stock e-bike battery | BMS current cap, hard cutoff |
| Swept flying wing, hanging pilot FBW | 0.5 Hz pendulum inside pitch-loop bandwidth |
| All-moving panels, cambered airfoil | 250 N·m hinge moments — actuator mass |
| Steppers / worm industrial gearboxes | power density, backlash (flutter path), holding heat |
| Spanwise pushrods / torsion shafts (4 m) | buckling, windup, ~3 kg/side |
| Spoilerons as primary control | no pitch, deadband + hysteresis |
| Balanced elevons (conventional) | survived on merit — became the final answer |
| Ducted fans | stopped-duct drag ≈ 2 points of L/D |
| Single pylon folding prop | single-point propulsion/control failure (owner call) |
| Four rotors | cruise efficiency; twins + fins cover the failure cases |
| One-piece sail over joints | structural unknown in fabric; serial rigging |

## Ideas that survived and where they live now

- Reflexed/low-Cm sections, pivot-at-AC logic → informs flap hinge moments
- D-nose + sail + battens construction → the wing build (spec §3)
- Morphing trailing edge → the camber flap, now compliance-critical (D-007)
- Torque-controlled actuators, current-as-load-sensing → FBW actuator spec
- Actuator-per-section, wiring-only across joints → fold-joint electrical
  interlock concept
- Thrust unloading for slow approach → landing assist (spec §9)
- Sub-scale first: mechanism testbed, not aerodynamic testbed → build plan

## Corrections carried forward from the review

- Launch was the unsolved half of the safety story → solved by wheels +
  thrust: 45–70 m grass roll (spec §6)
- Old mass budget (60.6 kg) was stale and configuration-lagged → rebuilt
  honestly at 103 kg with fold + gear + capsule (spec §4)
- Part 103 stall margin was ~3% at 130 kg and negative at real weight →
  wing grown to 13 m² + flap made mandatory (spec §5, D-007)
- Min-sink figures in the exploration were internally inconsistent
  (quoted above best-glide sink) → recomputed (spec §5)
- No ballistic chute in any budget → fitted; excluded from Part 103 empty
  weight, included in flying weight
- Propped-beam spar sizing assumed a rigid fin prop → fin stiffness is
  open risk #1 with a physical test gate (spec §10)

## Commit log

2026-08-31 Founding documents: spec v0.2, decision record, exploration history
    Concept definition for a single-seat folding electric assisted glider:
    joined-wing box that folds via two nested parallelogram linkages to a
    parking-space footprint, drives itself off-road to the launch point, and
    flies under Part 103 with fly-by-wire envelope protection.
    Claude-Session: https://claude.ai/code/session_01DJXq2mrFFeeSwQbeV2pnLG
2026-08-31 Fold mechanism v1 (model-verified) + mass audit with battery-as-residual-claimant
    - tools/fold_kinematics.py: parametric two-stage fold model with z-aware
    collision checking; found and resolved the chord-flip trap (forward
    scissor), root-stub swing-arc clearance, nacelle-over-canopy conflict,
    and the footwell hull constraint. Folded 3.91 x 2.46 x 2.08 m, clean
    through the full sequence, 18 mm min clearance.
    - docs/fold-mechanism.md: architecture, forced choices, joint loads,
    locks, interlocks, open items. docs/fold_sequence.png: sequence figure.
    - docs/mass-audit.md: constraint algebra (max battery = 115 - core),
    line-by-line justification, modular 4x0.9 kWh packs, measured W&B w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
2026-08-31 Parts log: battery evaluations (WattCycle, fraud listing, Fullymax 12S adopted for prototype)
    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
2026-09-01 Parts log: LiTech 13S6P RFQ candidate; soften bus freeze to 48V-class/54.6V-max
    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
2026-09-01 Adopt LiTech 13S6P as flight battery (6.8 kg confirmed, 177.9 Wh/kg); freeze 13S bus; update spec and mass audit
    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
2026-09-01 Parts log: reject BadAss 6245-155Kv (Kv/prop mismatch); freeze motor filter
    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
2026-09-01 Parts log: reject Alpha 80A 12S ESC (52.2V ceiling vs 13S bus); freeze ESC filter
    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
2026-09-01 Bus re-frozen at 12S: LiTech 12S6P RFQ, Alpha 80A ESC becomes candidate, motor filter Kv 55-70
    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
2026-09-01 Adopt P80 III KV100 as propulsion candidate; prop moves to 32in; amend motor filter to motor+prop pair
    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
2026-09-02 1:10 printed model: geometry generator, STLs, build plan
    - tools/model_geometry.py: lofts the real section (14.3%, 1.2% camber)
    into span-vertical 225 mm wing panels (inner, outer with 3 deg washout),
    fins, decalage root stubs, capsule pod, and hinge lugs; all watertight,
    all inside a 256 mm bed. models/1to10/*.stl + parts_report.json.
    - docs/model-1to10.md: what the model tests (fold with locks, config
    stability) and what it cannot (Re, flutter, sail), print counts incl.
    the chiral mirrored outer panels, hardware, mass/CG, phased test cards.
    - docs/model_1to10_preview.png: plate layout.
    Claude-Session: https://claude.ai/cod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
    [capsule_pod.stl, fin_blank.stl, hinge_lug.stl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]
2026-09-02 1:10 model: STEP solids (CadQuery) with lug pockets, Fusion 360 API build script
    - tools/model_step.py: B-rep STEP parts via OpenCascade; hinge-lug pockets
    at every panel end on the 25% chord line, spar on the twist axis, blind
    alignment pins, L/R outer panels mirrored correctly across the
    span-normal plane. models/1to10/step/*.step, all valid.
    - tools/fusion360/Shapeshifter1to10/: native parametric Fusion 360 script
    (user parameters ss_*), untested against a live Fusion instance.
    - docs: fixed the outer-panel mirror instruction (mirror along Z, not X),
    added the STL/STEP/Fusion workflow section.
    Claude-Session: https://clau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
    [capsule_pod.step, fin_blank.step, hinge_lug.step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]
